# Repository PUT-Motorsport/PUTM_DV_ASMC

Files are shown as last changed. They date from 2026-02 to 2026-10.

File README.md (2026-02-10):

# ASMC: Autonomous System Main Controller

## Project Overview
The **ASMC (Autonomous System Main Controller)** is a central electronic control unit designed for a Formula Student racing vehicle. Its primary objective is to integrate the critical subsystems required for autonomous operation in compliance with the **Formula Student Rules 2026**. 

This board serves as a robust interface between the high-level autonomous compute unit and the vehicle's hardware, ensuring safety, reliable power distribution, and real-time status signaling.

## Key Functionalities

### 1. Power Management & Distribution
* **Peripheral Supply**: Provides regulated and protected power to sensors, actuators, and processing units necessary for the Autonomous System (AS).
* **LVS Compliance**: Operates within the Low Voltage System (LVS) limits (max 60V DC) and ensures proper grounding to the chassis.
* **Overcurrent Protection**: Integrated protection for all connected devices to prevent hardware failure during dynamic disciplines.

### 2. Autonomous System Signaling (ASSI & AMI)
* **ASSI Control**: Drives three Autonomous System Status Indicators (ASSI) positioned on the sides and rear of the vehicle.
* **Visual Logic**: Implements mandatory lighting patterns (e.g., 2–5 Hz flashing for "Driving" and "Emergency" states).
* **Acoustic Warning**: Manages the intermittent sound signal (80–90 dBA) required during the "AS Emergency" state.
* **Mission Selection**: Interfaces with the Autonomous Mission Indicator (AMI) to allow manual mission selection and status feedback without external tools.

### 3. Safety & Braking Interface (ASB/EBS)
* **EBS Data Processing**: Receives and processes critical data from the Emergency Brake System (EBS).
* **SCS Monitoring**: Continuously monitors System Critical Signals (SCS). Any failure (e.g., open circuit or data corruption) triggers a safe state transition within <500ms.
* **SDC & RES Integration**: Interfaces with the Shutdown Circuit (SDC) and the Remote Emergency System (RES) to allow for immediate vehicle shutdown.

## Technical Compliance
Designed according to the **T14 (Autonomous System)** and **T15 (Autonomous System Brake)** sections of the FS 2026 rulebook.

* **AS Status Flowchart**: The board logic follows the mandatory state machine (Off, Ready, Driving, Emergency, Finished).
* **Failsafe Design**: Ensures that loss of power or signal defaults the vehicle to an "AS Emergency" state, engaging the mechanical brakes.
* **Data Logging**: Provides necessary signal outputs to the official Formula Student Data Logger for competition transparency.

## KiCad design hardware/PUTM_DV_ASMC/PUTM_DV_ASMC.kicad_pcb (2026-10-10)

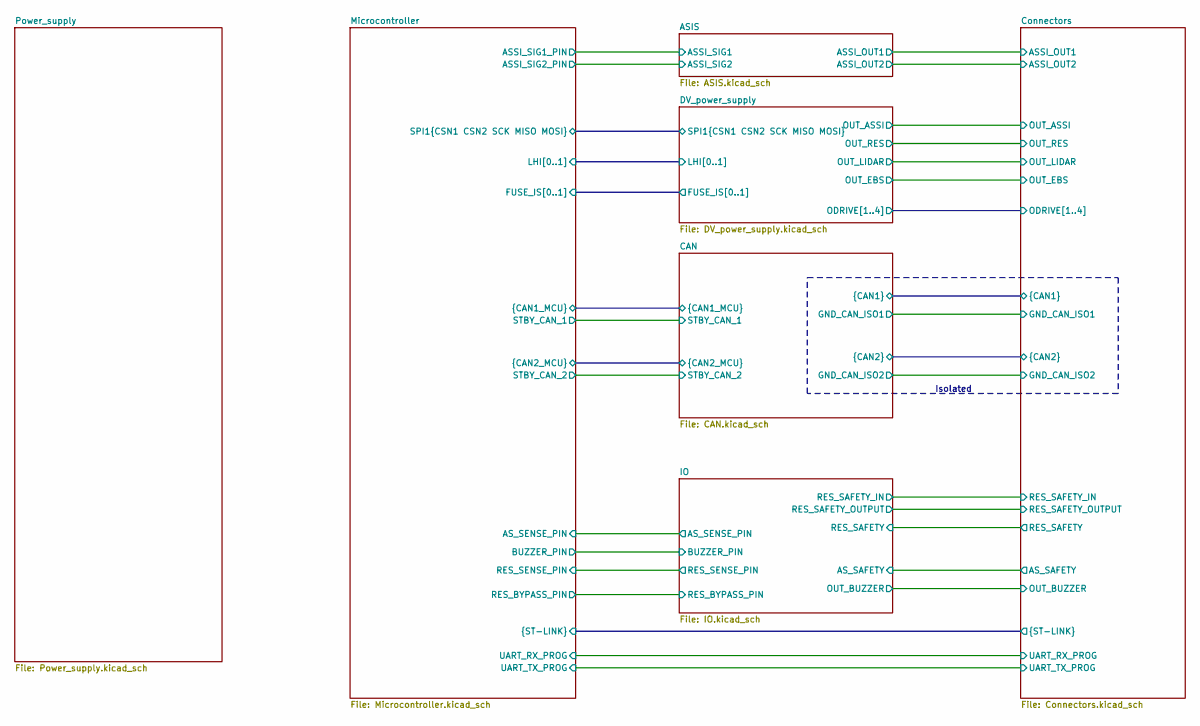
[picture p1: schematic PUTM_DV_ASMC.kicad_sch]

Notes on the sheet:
Isolated

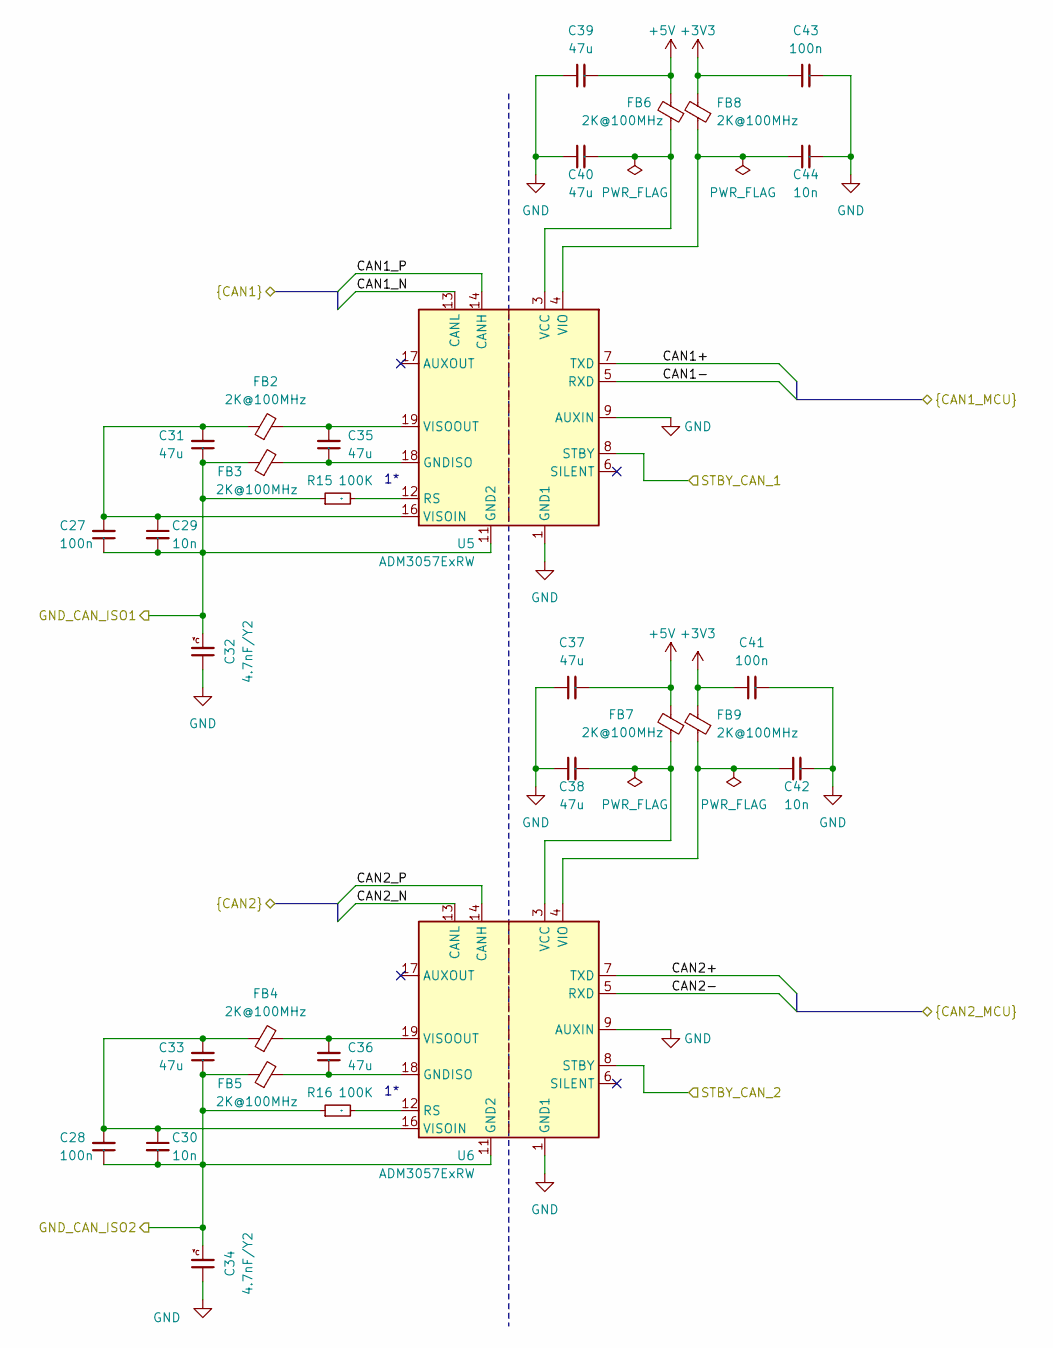
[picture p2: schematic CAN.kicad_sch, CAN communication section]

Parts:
C27, C28, C41, C43: 100n; C_0603_1608Metric_Pad1.08x0.95mm_HandSolder; Mouser Part Number .
C29, C30, C42, C44: 10n; C_0603_1608Metric_Pad1.08x0.95mm_HandSolder; Mouser Part Number .
C31, C33, C35, C36, C37, C38, C39, C40: 47u; C_0805_2012Metric_Pad1.18x1.45mm_HandSolder; Mouser Part Number .
C32, C34: 4.7nF/Y2; CAPC5728X280N; Mouser Part Number 791-S252B222K502CT
FB2, FB3, FB4, FB5, FB6, FB7, FB8, FB9: 2K@100MHz; L_0805_2012Metric_Pad1.05x1.20mm_HandSolder; Mouser Part Number 623-2508052027Y1
R15, R16: 100K; R_0603_1608Metric_Pad0.98x0.95mm_HandSolder; Mouser Part Number .
U5, U6: ADM3057ExRW; SOIC-20W_7.5x12.8mm_P1.27mm; Mouser Part Number 584-ADM3057EBRWZ

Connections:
+3V3: C41.1, C43.1, FB8.2, FB9.2; also elsewhere on the board
+5V: C37.2, C39.2, FB6.2, FB7.2; also elsewhere on the board
/CAN/CAN1+: U5.7 (TXD); also elsewhere on the board
/CAN/CAN1-: U5.5 (RXD); also elsewhere on the board
/CAN/CAN1_N: U5.13 (CANL); also elsewhere on the board
/CAN/CAN1_P: U5.14 (CANH); also elsewhere on the board
/CAN/CAN2+: U6.7 (TXD); also elsewhere on the board
/CAN/CAN2-: U6.5 (RXD); also elsewhere on the board
/CAN/CAN2_N: U6.13 (CANL); also elsewhere on the board
/CAN/CAN2_P: U6.14 (CANH); also elsewhere on the board
/CAN/GND_CAN_ISO1: C27.1, C29.2, C31.1, C32.2, FB3.1, R15.1, U5.11 (GND2), U5.15 (GND2); also elsewhere on the board
/CAN/GND_CAN_ISO2: C28.1, C30.2, C33.1, C34.2, FB5.1, R16.1, U6.11 (GND2), U6.15 (GND2); also elsewhere on the board
/CAN/STBY_CAN_1: U5.8 (STBY); also elsewhere on the board
/CAN/STBY_CAN_2: U6.8 (STBY); also elsewhere on the board
GND: C32.1, C34.1, C37.1, C38.1, C39.1, C40.1, C41.2, C42.2, C43.2, C44.2, U5.1 (GND1), U5.2 (GND1), U5.9 (AUXIN), U5.10 (GND1), U6.1 (GND1), U6.2 (GND1), U6.9 (AUXIN), U6.10 (GND1); also elsewhere on the board
unnamed: C35.1, FB3.2, U5.18 (GNDISO), U5.20 (GNDISO)
unnamed: C36.1, FB5.2, U6.18 (GNDISO), U6.20 (GNDISO)
unnamed: R15.2, U5.12 (RS)
unnamed: C40.2, FB6.1, U5.3 (VCC)
unnamed: C44.1, FB8.1, U5.4 (VIO)
unnamed: C27.2, C29.1, C31.2, FB2.1, U5.16 (VISOIN)
unnamed: C35.2, FB2.2, U5.19 (VISOOUT)
unnamed: R16.2, U6.12 (RS)
unnamed: C38.2, FB7.1, U6.3 (VCC)
unnamed: C42.1, FB9.1, U6.4 (VIO)
unnamed: C28.2, C30.1, C33.2, FB4.1, U6.16 (VISOIN)
unnamed: C36.2, FB4.2, U6.19 (VISOOUT)

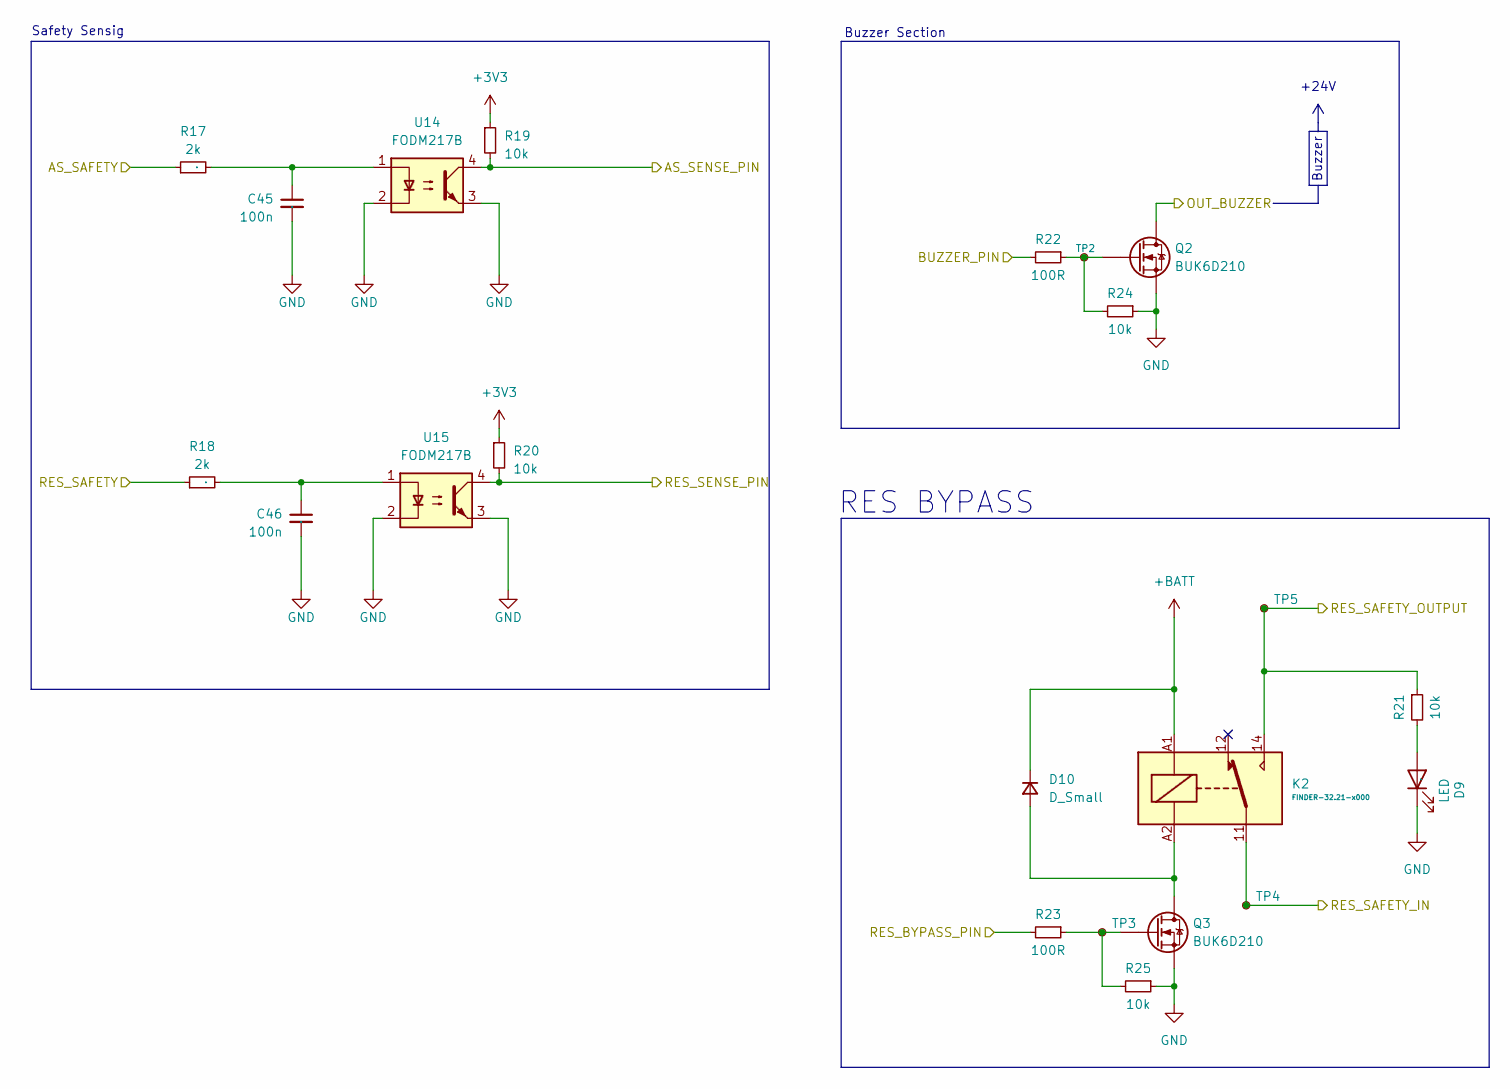
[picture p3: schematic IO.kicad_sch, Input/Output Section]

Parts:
C45, C46: 100n; C_0603_1608Metric_Pad1.08x0.95mm_HandSolder; Mouser Part Number .
D9: LED; LED_0603_1608Metric_Pad1.05x0.95mm_HandSolder; Mouser Part Number .
D10: D_Small; D_0805_2012Metric_Pad1.15x1.40mm_HandSolder
K2: FINDER-32.21-x000; Relay_SPDT_Finder_32.21-x000
Q2, Q3: BUK6D210; Diodes_UDFN2020-6_Type-F
R17, R18: 2k; R_0603_1608Metric_Pad0.98x0.95mm_HandSolder; Mouser Part Number .
R19, R20: 10k; R_0603_1608Metric_Pad0.98x0.95mm_HandSolder; Mouser Part Number .
R21: 10k; R_1206_3216Metric_Pad1.30x1.75mm_HandSolder
R22, R23: 100R; R_0603_1608Metric
R24, R25: 10k; R_0603_1608Metric
TP2: TestPoint_Small; TestPoint_Pad_D1.0mm
TP3, TP4, TP5: TestPoint_Small
U14, U15: FODM217B; SOP-4_4.4x2.6mm_P1.27mm; Mouser Part Number 512-FODM217B

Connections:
+3V3: R19.1, R20.1; also elsewhere on the board
+BATT: D10.1 (K), K2.A1; also elsewhere on the board
/Connectors/AS_SAFETY: R17.1; also elsewhere on the board
/Connectors/OUT_BUZZER: Q2.1 (D), Q2.2 (D), Q2.5 (D), Q2.6 (D), Q2.7 (D); also elsewhere on the board
/Connectors/RES_SAFETY: R18.1; also elsewhere on the board
/Connectors/RES_SAFETY_IN: K2.11, TP4.1; also elsewhere on the board
/Connectors/RES_SAFETY_OUTPUT: K2.14, R21.1, TP5.1; also elsewhere on the board
/IO/AS_SENSE_PIN: R19.2, U14.4; also elsewhere on the board
/IO/BUZZER_PIN: R22.2; also elsewhere on the board
/IO/RES_BYPASS_PIN: R23.2; also elsewhere on the board
/IO/RES_SENSE_PIN: R20.2, U15.4; also elsewhere on the board
GND: C45.2, C46.2, D9.1 (K), Q2.4 (S), Q2.8 (S), Q3.4 (S), Q3.8 (S), R24.1, R25.1, U14.2, U14.3, U15.2, U15.3; also elsewhere on the board
unnamed: C45.1, R17.2, U14.1
unnamed: C46.1, R18.2, U15.1
unnamed: D9.2 (A), R21.2
unnamed: D10.2 (A), K2.A2, Q3.1 (D), Q3.2 (D), Q3.5 (D), Q3.6 (D), Q3.7 (D)
unnamed: Q2.3 (G), R22.1, R24.2, TP2.1 (1_1)
unnamed: Q3.3 (G), R23.1, R25.2, TP3.1

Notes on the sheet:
+24V
Buzzer Section
Buzzer
Safety Sensig
RES BYPASS

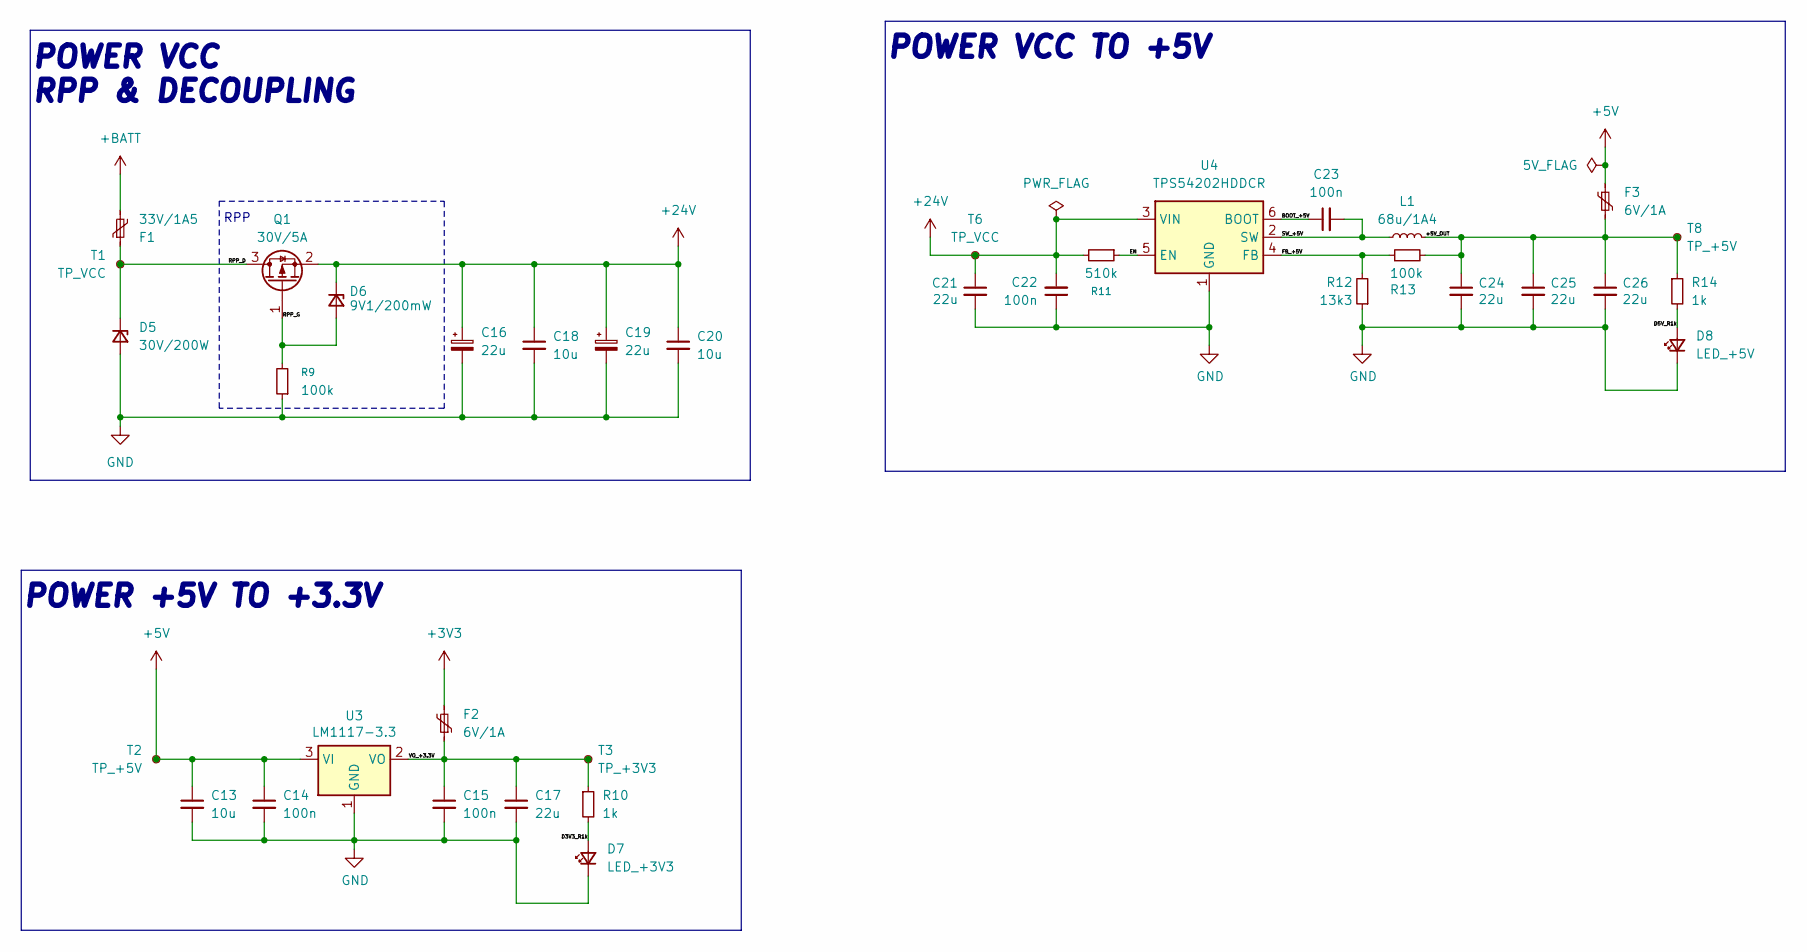
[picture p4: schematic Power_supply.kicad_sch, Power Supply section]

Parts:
C13, C18, C20: 10u; C_0805_2012Metric_Pad1.18x1.45mm_HandSolder; Mouser Part Number 81-GRM21BR61H106KE3L
C14, C15, C23: 100n; C_0603_1608Metric_Pad1.08x0.95mm_HandSolder; Mouser Part Number 81-GCJ188R71H104KA2D
C16, C19: 22u; CP_Elec_5x5.8; Mouser Part Number 647-UCM1H220MCL1GS
C17: 22u; C_0805_2012Metric_Pad1.18x1.45mm_HandSolder; Mouser Part Number 810-C2012X5R1V226MAC
C21, C24, C25, C26: 22u; C_0805_2012Metric_Pad1.18x1.45mm_HandSolder; Manufacturer_Part_Number CL21A107MQYNNWE; Mouser Part Number 810-C2012X5R1V226MAC
C22: 100n; C_0603_1608Metric_Pad1.08x0.95mm_HandSolder; Manufacturer_Part_Number C0603C104J3RACTU; Mouser Part Number 81-GCJ188R71H104KA2D
D5: 30V/200W; D_SOD-123; Mouser Part Number 750-TV02W260-G
D6: 9V1/200mW; D_SOD-323_HandSoldering; Mouser Part Number 833-MMXZ5239B-TP
D7: LED_+3V3; LED_0603_1608Metric_Pad1.05x0.95mm_HandSolder
D8: LED_+5V; LED_0603_1608Metric_Pad1.05x0.95mm_HandSolder
F1: 33V/1A5; Fuse_2920_7451Metric_Pad2.10x5.45mm_HandSolder; Mouser Part Number 530-0ZCF0075AF2C
F2, F3: 6V/1A; Fuse_0805_2012Metric_Pad1.15x1.40mm_HandSolder; Mouser Part Number 650-PICOSMDC050S-2
L1: 68u/1A4; L_TDK_VLS6045EX_VLS6045AF; Mouser Part Number 810-VLS6045EX-680M
Q1: 30V/5A; SOT-23-3; Mouser Part Number 78-SI2347DS-T1-GE3
R9: 100k; R_0603_1608Metric_Pad0.98x0.95mm_HandSolder; Mouser Part Number 71-CRCW0603100KFKEAH
R10, R14: 1k; R_0603_1608Metric_Pad0.98x0.95mm_HandSolder; Mouser Part Number 71-CRCW0603-1.0K-E3
R11: 510k; R_0603_1608Metric_Pad0.98x0.95mm_HandSolder; Mouser Part Number 71-CRCW0603J-510K-E3
R12: 13k3; R_0603_1608Metric_Pad0.98x0.95mm_HandSolder; Manufacturer_Part_Number RT0603DRE0713K3L; Mouser Part Number 71-CRCW0603-13.3K-E3
R13: 100k; R_0603_1608Metric_Pad0.98x0.95mm_HandSolder; Manufacturer_Part_Number RT0603DRE07100KL; Mouser Part Number 71-CRCW0603100KFKEAH
T1, T6: TP_VCC; TestPoint_Pad_1.0x1.0mm
T2, T8: TP_+5V; TestPoint_Pad_1.0x1.0mm
T3: TP_+3V3; TestPoint_Pad_1.0x1.0mm
U3: LM1117-3.3; SOT-223-3_TabPin2; Mouser Part Number 926-LM1117MPX3.3NOPB
U4: TPS54202HDDCR; SOT-23-6_Handsoldering; Mouser Part Number 595-TPS54202HDDCR

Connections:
+3V3: F2.2; also elsewhere on the board
+5V: C13.1, C14.1, F3.1, T2.1 (1_1), U3.3 (VI); also elsewhere on the board
+24V: C16.1, C18.1, C19.1, C20.1, C21.1, C22.2, D6.1 (K), Q1.2 (S), R11.2, T6.1 (1_1), U4.3 (VIN)
+BATT: F1.2; also elsewhere on the board
/Power_supply/+5V_OUT: C24.1, C25.1, C26.1, F3.2, L1.2, R13.2, R14.1, T8.1 (1_1)
/Power_supply/BOOT_+5V: C23.1, U4.6 (BOOT)
/Power_supply/D3V3_R1k: D7.2 (A), R10.2
/Power_supply/D5V_R1k: D8.2 (A), R14.2
/Power_supply/EN: R11.1, U4.5 (EN)
/Power_supply/FB_+5V: R12.2, R13.1, U4.4 (FB)
/Power_supply/RPP_D: D5.1 (K), F1.1, Q1.3 (D), T1.1 (1_1)
/Power_supply/RPP_G: D6.2 (A), Q1.1 (G), R9.2
/Power_supply/SW_+5V: C23.2, L1.1, U4.2 (SW)
/Power_supply/VO_+3.3V: C15.1, C17.1, F2.1, R10.1, T3.1 (1_1), U3.2 (VO)
GND: C13.2, C14.2, C15.2, C16.2, C17.2, C18.2, C19.2, C20.2, C21.2, C22.1, C24.2, C25.2, C26.2, D5.2 (A), D7.1 (K), D8.1 (K), R9.1, R12.1, U3.1 (GND), U4.1 (GND); also elsewhere on the board

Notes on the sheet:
POWER +5V TO +3.3V
POWER VCC RPP & DECOUPLING
POWER VCC TO +5V
RPP

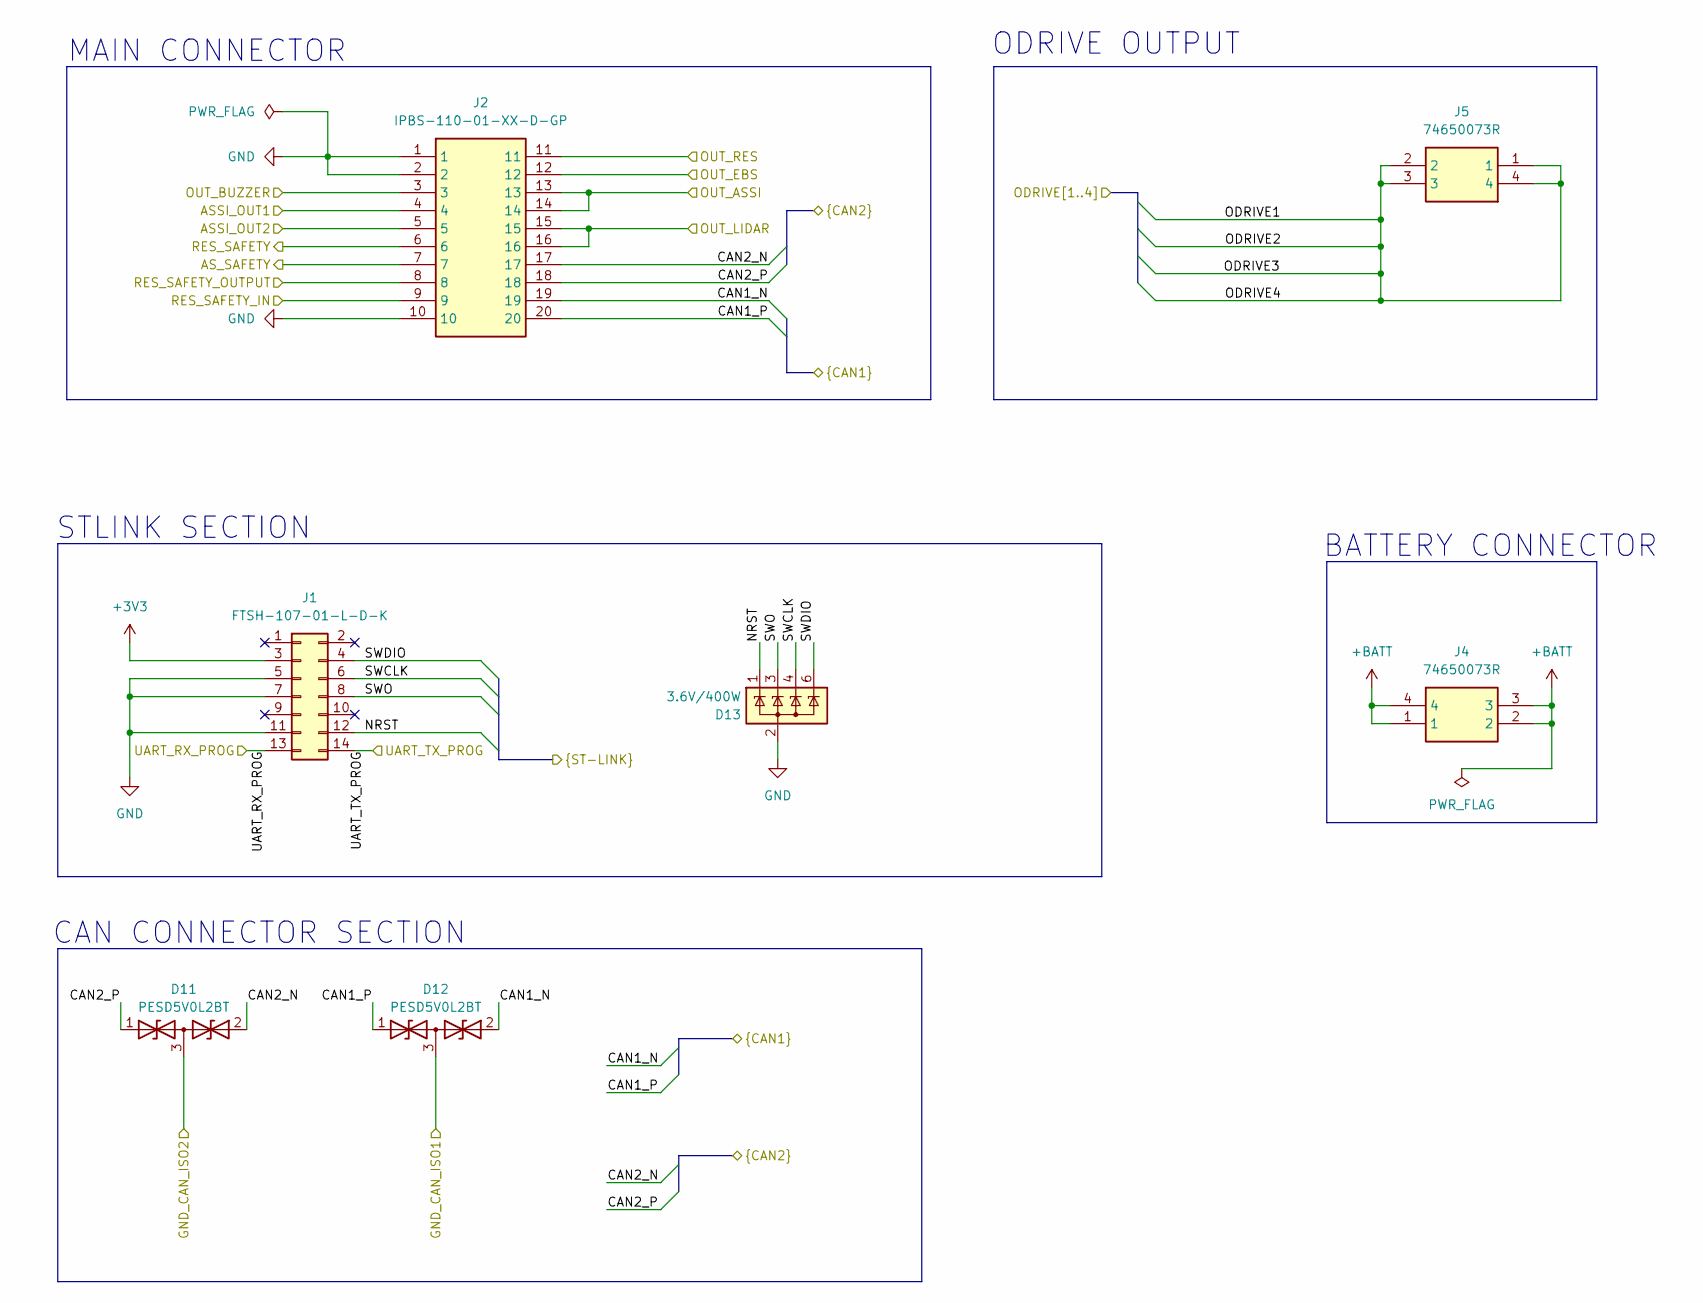
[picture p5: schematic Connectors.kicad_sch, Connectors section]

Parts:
D11, D12: PESD5V0L2BT; SOT-23_Handsoldering; Mouser Part Number 771-PESD5V0L2BT-QR
D13: 3.6V/400W; SOT-23-6; Manufacturer_Part_Number ESDS304DBVR; Mouser Part Number 595-ESDS304DBVR
J1: FTSH-107-01-L-D-K; FTSH-107-XX-YYY-D-K; Mouser Part Number 200-FTSH10701LDK
J2: IPBS-110-01-XX-D-GP; IPBS11001TDGP; PARTREV M; Mouser Part Number 200-IPBS11001TDGP
J4, J5: 74650073R; Mouser Part Number 710-74650073R

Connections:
+3V3: J1.3; also elsewhere on the board
+BATT: J4.1, J4.2, J4.3, J4.4; also elsewhere on the board
/ASIS/ASSI_OUT1: J2.4; also elsewhere on the board
/ASIS/ASSI_OUT2: J2.5; also elsewhere on the board
/CAN/CAN1_N: D12.2 (A2), J2.19; also elsewhere on the board
/CAN/CAN1_P: D12.1 (A1), J2.20; also elsewhere on the board
/CAN/CAN2_N: D11.2 (A2), J2.17; also elsewhere on the board
/CAN/CAN2_P: D11.1 (A1), J2.18; also elsewhere on the board
/CAN/GND_CAN_ISO1: D12.3 (common); also elsewhere on the board
/CAN/GND_CAN_ISO2: D11.3 (common); also elsewhere on the board
/Connectors/AS_SAFETY: J2.7; also elsewhere on the board
/Connectors/NRST: D13.1 (A), J1.12; also elsewhere on the board
/Connectors/ODRIVE4: J5.1, J5.2, J5.3, J5.4; also elsewhere on the board
/Connectors/OUT_ASSI: J2.13, J2.14; also elsewhere on the board
/Connectors/OUT_BUZZER: J2.3; also elsewhere on the board
/Connectors/OUT_EBS: J2.12; also elsewhere on the board
/Connectors/OUT_LIDAR: J2.15, J2.16; also elsewhere on the board
/Connectors/OUT_RES: J2.11; also elsewhere on the board
/Connectors/RES_SAFETY: J2.6; also elsewhere on the board
/Connectors/RES_SAFETY_IN: J2.9; also elsewhere on the board
/Connectors/RES_SAFETY_OUTPUT: J2.8; also elsewhere on the board
/Connectors/SWCLK: D13.4 (A), J1.6; also elsewhere on the board
/Connectors/SWDIO: D13.6 (A), J1.4; also elsewhere on the board
/Connectors/SWO: D13.3 (A), J1.8; also elsewhere on the board
/Connectors/UART_RX_PROG: J1.13; also elsewhere on the board
/Connectors/UART_TX_PROG: J1.14; also elsewhere on the board
GND: D13.2 (K), D13.5 (NC), J1.5, J1.7, J1.11, J2.1, J2.2, J2.10; also elsewhere on the board

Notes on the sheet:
BATTERY CONNECTOR
STLINK SECTION
CAN CONNECTOR SECTION
MAIN CONNECTOR
ODRIVE OUTPUT

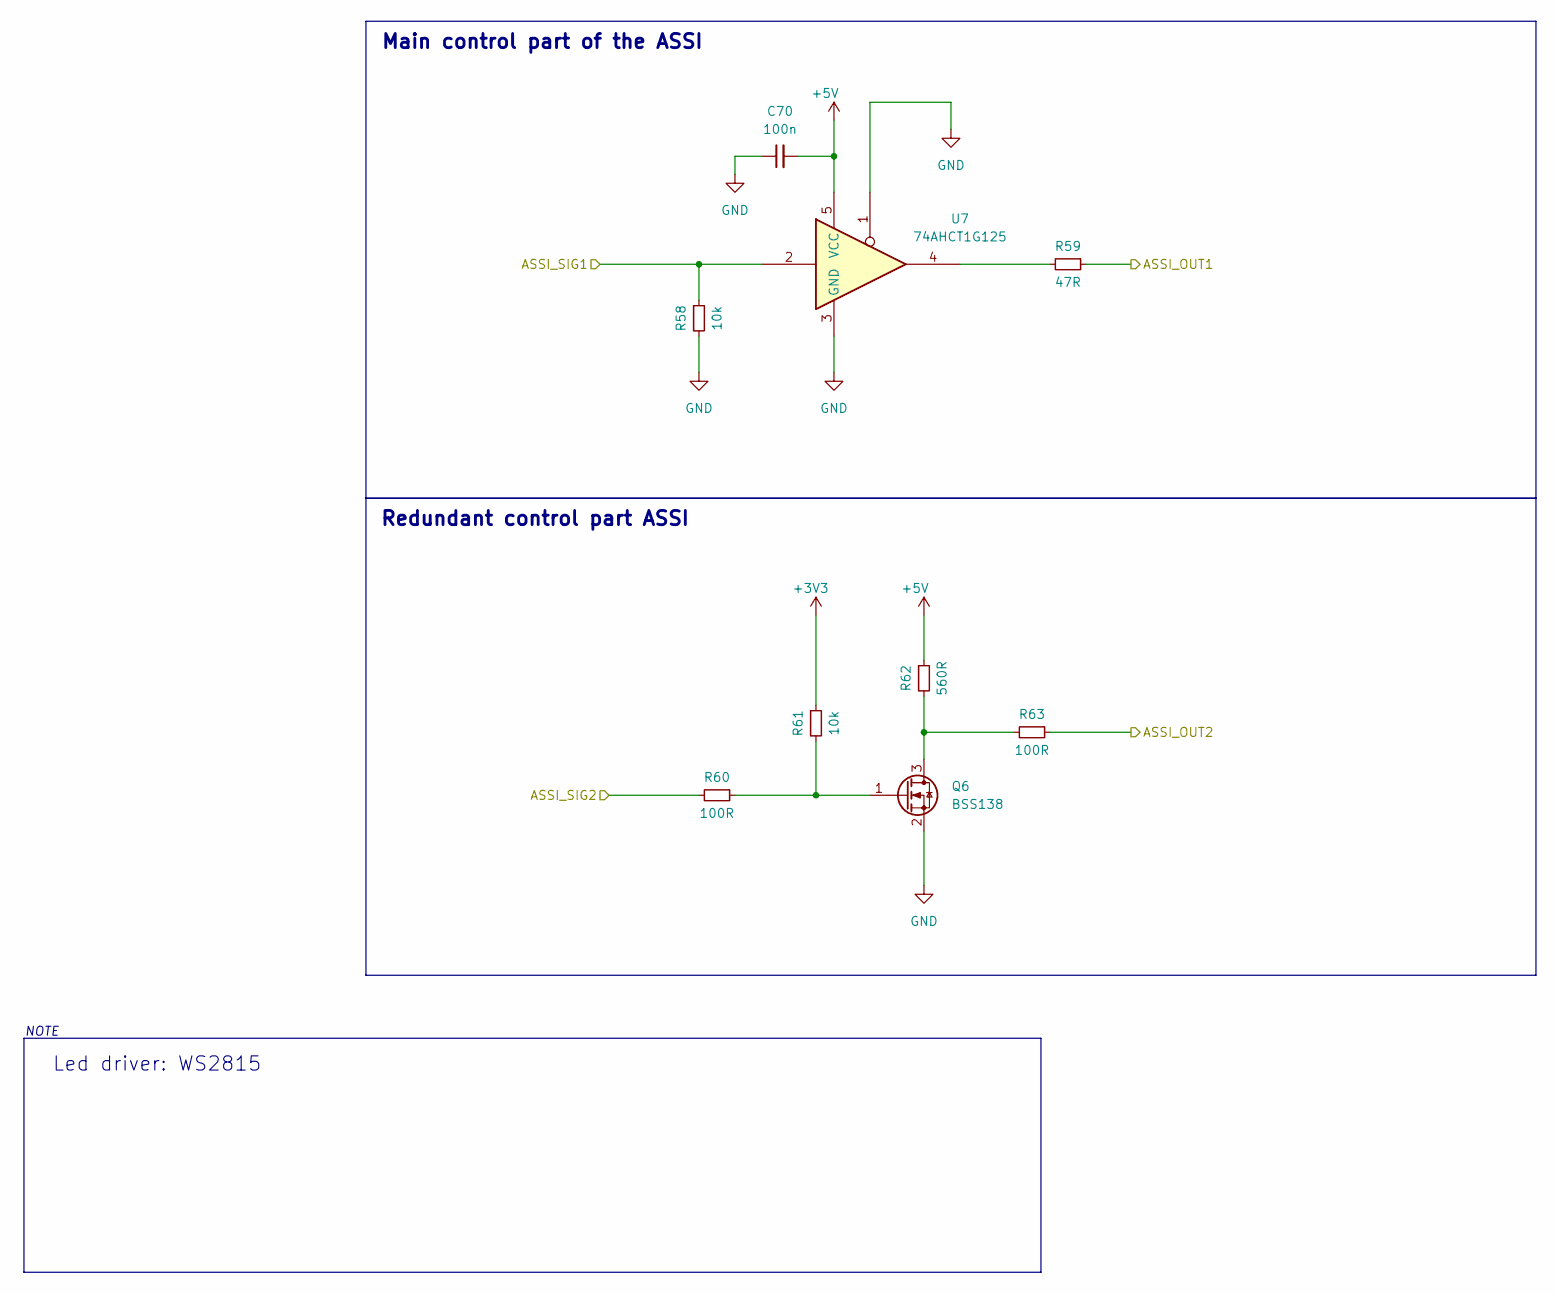
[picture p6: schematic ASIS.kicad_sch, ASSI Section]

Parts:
C70: 100n; C_0603_1608Metric_Pad1.08x0.95mm_HandSolder; Mouser Part Number .
Q6: BSS138; SOT-23
R58, R61: 10k; R_0603_1608Metric
R59: 47R; R_0603_1608Metric
R60, R63: 100R; R_0603_1608Metric
R62: 560R; R_0603_1608Metric
U7: 74AHCT1G125; SOT-23-5

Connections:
+3V3: R61.1; also elsewhere on the board
+5V: C70.2, R62.1, U7.5 (VCC); also elsewhere on the board
/ASIS/ASSI_OUT1: R59.1; also elsewhere on the board
/ASIS/ASSI_OUT2: R63.1; also elsewhere on the board
/ASIS/ASSI_SIG1: R58.1, U7.2; also elsewhere on the board
/ASIS/ASSI_SIG2: R60.2; also elsewhere on the board
GND: C70.1, Q6.2 (S), R58.2, U7.1, U7.3 (GND); also elsewhere on the board
unnamed: Q6.3 (D), R62.2, R63.2
unnamed: Q6.1 (G), R60.1, R61.2
unnamed: R59.2, U7.4

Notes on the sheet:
Led driver: WS2815
Redundant control part ASSI
Main control part of the ASSI
NOTE

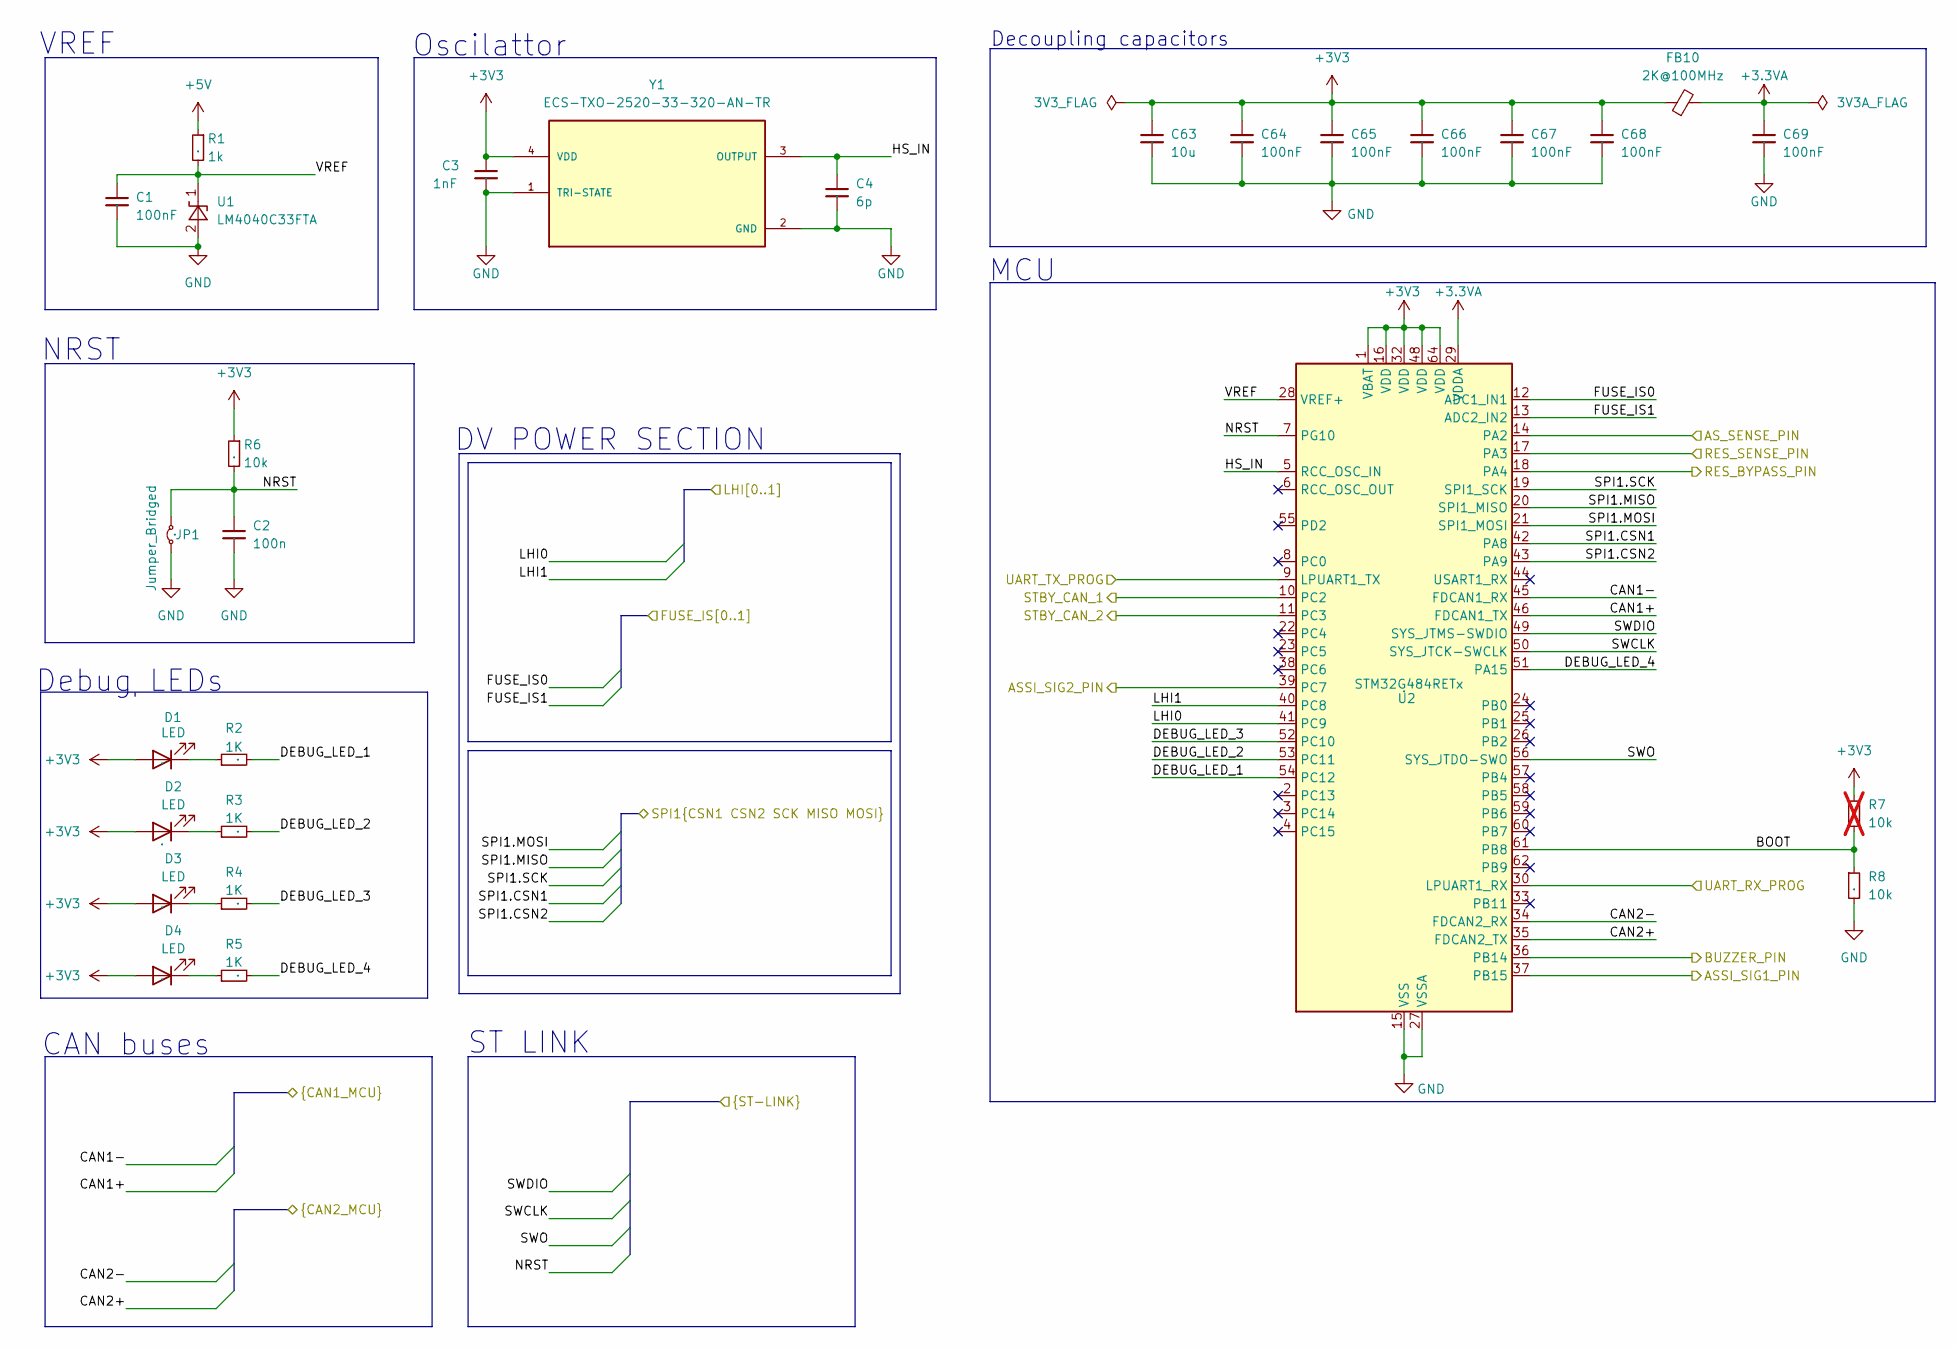
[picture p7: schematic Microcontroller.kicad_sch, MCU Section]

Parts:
C1, C64, C65, C66, C67, C68, C69: 100nF; C_0603_1608Metric_Pad1.08x0.95mm_HandSolder; Mouser Part Number .
C2: 100n; C_0603_1608Metric; Mouser Part Number .
C3: 1nF; C_0603_1608Metric_Pad1.08x0.95mm_HandSolder; Mouser Part Number .
C4: 6p; C_0603_1608Metric_Pad1.08x0.95mm_HandSolder; Mouser Part Number .
C63: 10u; C_0805_2012Metric_Pad1.18x1.45mm_HandSolder; Mouser Part Number .
D1, D2, D3, D4: LED; LED_0603_1608Metric_Pad1.05x0.95mm_HandSolder; Mouser Part Number .
FB10: 2K@100MHz; L_0805_2012Metric_Pad1.05x1.20mm_HandSolder; Mouser Part Number 623-2508052027Y1
JP1: Jumper_Bridged; SolderJumper-2_P1.3mm_Open_TrianglePad1.0x1.5mm; Mouser Part Number .
R1: 1k; R_0603_1608Metric; Mouser Part Number .
R2, R3, R4, R5: 1K; R_0603_1608Metric_Pad0.98x0.95mm_HandSolder; Mouser Part Number .
R6, R8: 10k; R_0603_1608Metric; Mouser Part Number .
R7: 10k; R_0603_1608Metric; Mouser Part Number .; not fitted
U1: LM4040C33FTA; SOT-23; Mouser Part Number 621-LM4040C33FTA
U2: STM32G484RETx; LQFP-64_10x10mm_P0.5mm; Mouser Part Number .
Y1: ECS-TXO-2520-33-320-AN-TR; OSC_ECS-TXO-2520-33-320-AN-TR; PARTREV 2017

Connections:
+3.3VA: C69.1, FB10.2, U2.29 (VDDA)
+3V3: C3.1, C63.1, C64.1, C65.1, C66.1, C67.1, C68.1, D1.2 (A), D2.2 (A), D3.2 (A), D4.2 (A), FB10.1, R6.1, R7.1, U2.1 (VBAT), U2.16 (VDD), U2.32 (VDD), U2.48 (VDD), U2.64 (VDD), Y1.4 (VDD); also elsewhere on the board
+5V: R1.1; also elsewhere on the board
/ASIS/ASSI_SIG1: U2.37 (PB15); also elsewhere on the board
/ASIS/ASSI_SIG2: U2.39 (PC7); also elsewhere on the board
/CAN/CAN1+: U2.46 (FDCAN1_TX); also elsewhere on the board
/CAN/CAN1-: U2.45 (FDCAN1_RX); also elsewhere on the board
/CAN/CAN2+: U2.35 (FDCAN2_TX); also elsewhere on the board
/CAN/CAN2-: U2.34 (FDCAN2_RX); also elsewhere on the board
/CAN/STBY_CAN_1: U2.10 (PC2); also elsewhere on the board
/CAN/STBY_CAN_2: U2.11 (PC3); also elsewhere on the board
/Connectors/NRST: C2.1, JP1.2 (B), R6.2, U2.7 (PG10); also elsewhere on the board
/Connectors/SWCLK: U2.50 (SYS_JTCK-SWCLK); also elsewhere on the board
/Connectors/SWDIO: U2.49 (SYS_JTMS-SWDIO); also elsewhere on the board
/Connectors/SWO: U2.56 (SYS_JTDO-SWO); also elsewhere on the board
/Connectors/UART_RX_PROG: U2.30 (LPUART1_RX); also elsewhere on the board
/Connectors/UART_TX_PROG: U2.9 (LPUART1_TX); also elsewhere on the board
/DV_power_supply/FUSE_IS0: U2.12 (ADC1_IN1); also elsewhere on the board
/DV_power_supply/FUSE_IS1: U2.13 (ADC2_IN2); also elsewhere on the board
/DV_power_supply/LHI0: U2.41 (PC9); also elsewhere on the board
/DV_power_supply/LHI1: U2.40 (PC8); also elsewhere on the board
/DV_power_supply/SPI1.CSN1: U2.42 (PA8); also elsewhere on the board
/DV_power_supply/SPI1.CSN2: U2.43 (PA9); also elsewhere on the board
/DV_power_supply/SPI1.MISO: U2.20 (SPI1_MISO); also elsewhere on the board
/DV_power_supply/SPI1.MOSI: U2.21 (SPI1_MOSI); also elsewhere on the board
/DV_power_supply/SPI1.SCK: U2.19 (SPI1_SCK); also elsewhere on the board
/IO/AS_SENSE_PIN: U2.14 (PA2); also elsewhere on the board
/IO/BUZZER_PIN: U2.36 (PB14); also elsewhere on the board
/IO/RES_BYPASS_PIN: U2.18 (PA4); also elsewhere on the board
/IO/RES_SENSE_PIN: U2.17 (PA3); also elsewhere on the board
/Microcontroller/BOOT: R7.2, R8.1, U2.61 (PB8)
/Microcontroller/DEBUG_LED_1: R2.2, U2.54 (PC12)
/Microcontroller/DEBUG_LED_2: R3.2, U2.53 (PC11)
/Microcontroller/DEBUG_LED_3: R4.2, U2.52 (PC10)
/Microcontroller/DEBUG_LED_4: R5.2, U2.51 (PA15)
/Microcontroller/HS_IN: C4.1, U2.5 (RCC_OSC_IN), Y1.3 (OUTPUT)
/Microcontroller/VREF: C1.1, R1.2, U1.1 (K), U2.28 (VREF+)
GND: C1.2, C2.2, C3.2, C4.2, C63.2, C64.2, C65.2, C66.2, C67.2, C68.2, C69.2, JP1.1 (A), R8.2, U1.2 (A), U2.15 (VSS), U2.27 (VSSA), U2.31 (VSS), U2.47 (VSS), U2.63 (VSS), Y1.1 (TRI-STATE), Y1.2 (GND); also elsewhere on the board
unnamed: D1.1 (K), R2.1
unnamed: D2.1 (K), R3.1
unnamed: D3.1 (K), R4.1
unnamed: D4.1 (K), R5.1

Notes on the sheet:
DV POWER SECTION
NRST
Decoupling capacitors
Debug LEDs
CAN buses
Oscilattor
MCU
VREF
ST LINK

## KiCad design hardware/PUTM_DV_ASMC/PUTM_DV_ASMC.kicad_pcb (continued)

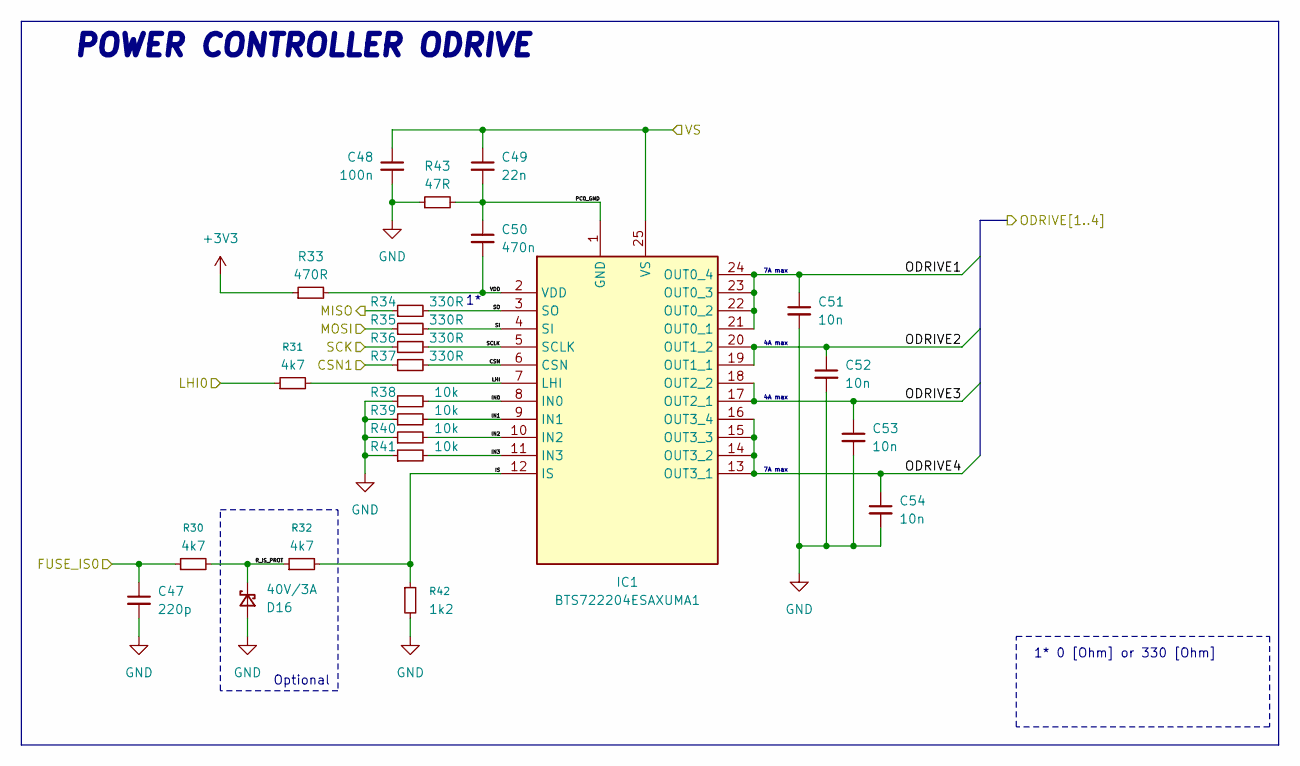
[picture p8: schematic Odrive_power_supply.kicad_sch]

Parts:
C47: 220p; C_0603_1608Metric_Pad1.08x0.95mm_HandSolder; Mouser Part Number 81-GCM1885C1H221JA6J
C48: 100n; C_0603_1608Metric_Pad1.08x0.95mm_HandSolder; Mouser Part Number 81-GCJ188R71H104KA2D
C49: 22n; C_0603_1608Metric_Pad1.08x0.95mm_HandSolder; Mouser Part Number GCE188R71H223KA01D
C50: 470n; C_0603_1608Metric_Pad1.08x0.95mm_HandSolder; Mouser Part Number 810-C1608X7R1H474K0E
C51, C52, C53, C54: 10n; C_0603_1608Metric_Pad1.08x0.95mm_HandSolder; Mouser Part Number 81-GCE188R71H103KA1D
D16: 40V/3A; D_SOD-123F; Mouser Part Number 637-SKL34
IC1: BTS722204ESAXUMA1; SOP65P600X115-25N; Mouser Part Number 726-BTS722204ESAXUMA
R30, R31, R32: 4k7; R_0603_1608Metric_Pad0.98x0.95mm_HandSolder; Mouser Part Number 71-CRCW0603-4.7K-E3
R33: 470R; R_0603_1608Metric_Pad0.98x0.95mm_HandSolder; Mouser Part Number 71-CRCW0603J-470-E3
R34, R35, R36, R37: 330R; R_0603_1608Metric_Pad0.98x0.95mm_HandSolder; Mouser Part Number 71-CRCW0603-330-E3
R38, R39, R40, R41: 10k; R_0603_1608Metric_Pad0.98x0.95mm_HandSolder; Mouser Part Number 71-CRCW060310K0FKEAH
R42: 1k2; R_0603_1608Metric_Pad0.98x0.95mm_HandSolder; Mouser Part Number 71-CRCW0603-1.2K-E3
R43: 47R; R_0603_1608Metric_Pad0.98x0.95mm_HandSolder; Mouser Part Number 71-RCS060347R0JNEA

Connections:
+3V3: R33.1; also elsewhere on the board
+BATT: C48.1, C49.1, IC1.25 (VS); also elsewhere on the board
/Connectors/ODRIVE4: C51.1, C52.1, C53.1, C54.1, IC1.13 (OUT3_1), IC1.14 (OUT3_2), IC1.15 (OUT3_3), IC1.16 (OUT3_4), IC1.17 (OUT2_1), IC1.18 (OUT2_2), IC1.19 (OUT1_1), IC1.20 (OUT1_2), IC1.21 (OUT0_1), IC1.22 (OUT0_2), IC1.23 (OUT0_3), IC1.24 (OUT0_4); also elsewhere on the board
/DV_power_supply/FUSE_IS0: C47.1, R30.1; also elsewhere on the board
/DV_power_supply/LHI0: R31.1; also elsewhere on the board
/DV_power_supply/Odrive_power_supply/CSN: IC1.6 (CSN), R37.2
/DV_power_supply/Odrive_power_supply/IN0: IC1.8 (IN0), R38.2
/DV_power_supply/Odrive_power_supply/IN1: IC1.9 (IN1), R39.2
/DV_power_supply/Odrive_power_supply/IN2: IC1.10 (IN2), R40.2
/DV_power_supply/Odrive_power_supply/IN3: IC1.11 (IN3), R41.2
/DV_power_supply/Odrive_power_supply/IS: IC1.12 (IS), R32.2, R42.1
/DV_power_supply/Odrive_power_supply/LHI: IC1.7 (LHI), R31.2
/DV_power_supply/Odrive_power_supply/PC0_GND: C49.2, C50.1, IC1.1 (GND), R43.2
/DV_power_supply/Odrive_power_supply/R_IS_PROT: D16.1 (K), R30.2, R32.1
/DV_power_supply/Odrive_power_supply/SCLK: IC1.5 (SCLK), R36.2
/DV_power_supply/Odrive_power_supply/SI: IC1.4 (SI), R35.2
/DV_power_supply/Odrive_power_supply/SO: IC1.3 (SO), R34.2
/DV_power_supply/Odrive_power_supply/VDD: C50.2, IC1.2 (VDD), R33.2
/DV_power_supply/SPI1.CSN1: R37.1; also elsewhere on the board
/DV_power_supply/SPI1.MISO: R34.1; also elsewhere on the board
/DV_power_supply/SPI1.MOSI: R35.1; also elsewhere on the board
/DV_power_supply/SPI1.SCK: R36.1; also elsewhere on the board
GND: C47.2, C48.2, C51.2, C52.2, C53.2, C54.2, D16.2 (A), R38.1, R39.1, R40.1, R41.1, R42.2, R43.1; also elsewhere on the board

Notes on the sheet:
4A max
Optional
1* 0 [Ohm] or 330 [Ohm]
POWER CONTROLLER ODRIVE
7A max

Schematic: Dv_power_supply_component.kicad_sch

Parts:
C55: 220p; C_0603_1608Metric_Pad1.08x0.95mm_HandSolder; Mouser Part Number 81-GCM1885C1H221JA6J
C56: 100n; C_0603_1608Metric_Pad1.08x0.95mm_HandSolder; Mouser Part Number 81-GCJ188R71H104KA2D
C57: 22n; C_0603_1608Metric_Pad1.08x0.95mm_HandSolder; Mouser Part Number GCE188R71H223KA01D
C58: 470n; C_0603_1608Metric_Pad1.08x0.95mm_HandSolder; Mouser Part Number 810-C1608X7R1H474K0E
C59, C60, C61, C62: 10n; C_0603_1608Metric_Pad1.08x0.95mm_HandSolder; Mouser Part Number 81-GCE188R71H103KA1D
D17: 40V/3A; D_SOD-123F; Mouser Part Number 637-SKL34
IC2: BTS722204ESAXUMA1; SOP65P600X115-25N; Mouser Part Number 726-BTS722204ESAXUMA
R44, R45, R46: 4k7; R_0603_1608Metric_Pad0.98x0.95mm_HandSolder; Mouser Part Number 71-CRCW0603-4.7K-E3
R47: 470R; R_0603_1608Metric_Pad0.98x0.95mm_HandSolder; Mouser Part Number 71-CRCW0603J-470-E3
R48, R49, R50, R51: 330R; R_0603_1608Metric_Pad0.98x0.95mm_HandSolder; Mouser Part Number 71-CRCW0603-330-E3
R52, R53, R54, R55: 10k; R_0603_1608Metric_Pad0.98x0.95mm_HandSolder; Mouser Part Number 71-CRCW060310K0FKEAH
R56: 1k2; R_0603_1608Metric_Pad0.98x0.95mm_HandSolder; Mouser Part Number 71-CRCW0603-1.2K-E3
R57: 47R; R_0603_1608Metric_Pad0.98x0.95mm_HandSolder; Mouser Part Number 71-RCS060347R0JNEA

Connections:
+3V3: R47.1; also elsewhere on the board
+BATT: C56.1, C57.1, IC2.25 (VS); also elsewhere on the board
/Connectors/OUT_ASSI: C60.1, IC2.19 (OUT1_1), IC2.20 (OUT1_2); also elsewhere on the board
/Connectors/OUT_EBS: C61.1, IC2.17 (OUT2_1), IC2.18 (OUT2_2); also elsewhere on the board
/Connectors/OUT_LIDAR: C59.1, IC2.21 (OUT0_1), IC2.22 (OUT0_2), IC2.23 (OUT0_3), IC2.24 (OUT0_4); also elsewhere on the board
/Connectors/OUT_RES: C62.1, IC2.13 (OUT3_1), IC2.14 (OUT3_2), IC2.15 (OUT3_3), IC2.16 (OUT3_4); also elsewhere on the board
/DV_power_supply/Dv_power_supply_component/CSN: IC2.6 (CSN), R51.2
/DV_power_supply/Dv_power_supply_component/IN0: IC2.8 (IN0), R52.2
/DV_power_supply/Dv_power_supply_component/IN1: IC2.9 (IN1), R53.2
/DV_power_supply/Dv_power_supply_component/IN2: IC2.10 (IN2), R54.2
/DV_power_supply/Dv_power_supply_component/IN3: IC2.11 (IN3), R55.2
/DV_power_supply/Dv_power_supply_component/IS: IC2.12 (IS), R46.2, R56.1
/DV_power_supply/Dv_power_supply_component/LHI: IC2.7 (LHI), R45.2
/DV_power_supply/Dv_power_supply_component/PC0_GND: C57.2, C58.1, IC2.1 (GND), R57.2
/DV_power_supply/Dv_power_supply_component/R_IS_PROT: D17.1 (K), R44.2, R46.1
/DV_power_supply/Dv_power_supply_component/SCLK: IC2.5 (SCLK), R50.2
/DV_power_supply/Dv_power_supply_component/SI: IC2.4 (SI), R49.2
/DV_power_supply/Dv_power_supply_component/SO: IC2.3 (SO), R48.2
/DV_power_supply/Dv_power_supply_component/VDD: C58.2, IC2.2 (VDD), R47.2
/DV_power_supply/FUSE_IS1: C55.1, R44.1; also elsewhere on the board
/DV_power_supply/LHI1: R45.1; also elsewhere on the board
/DV_power_supply/SPI1.CSN2: R51.1; also elsewhere on the board
/DV_power_supply/SPI1.MISO: R48.1; also elsewhere on the board
/DV_power_supply/SPI1.MOSI: R49.1; also elsewhere on the board
/DV_power_supply/SPI1.SCK: R50.1; also elsewhere on the board
GND: C55.2, C56.2, C59.2, C60.2, C61.2, C62.2, D17.2 (A), R52.1, R53.1, R54.1, R55.1, R56.2, R57.1; also elsewhere on the board

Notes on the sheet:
POWER CONTROLLER DV COMPONENTS
1* 0 [Ohm] or 330 [Ohm]
7A max
Optional
4A max

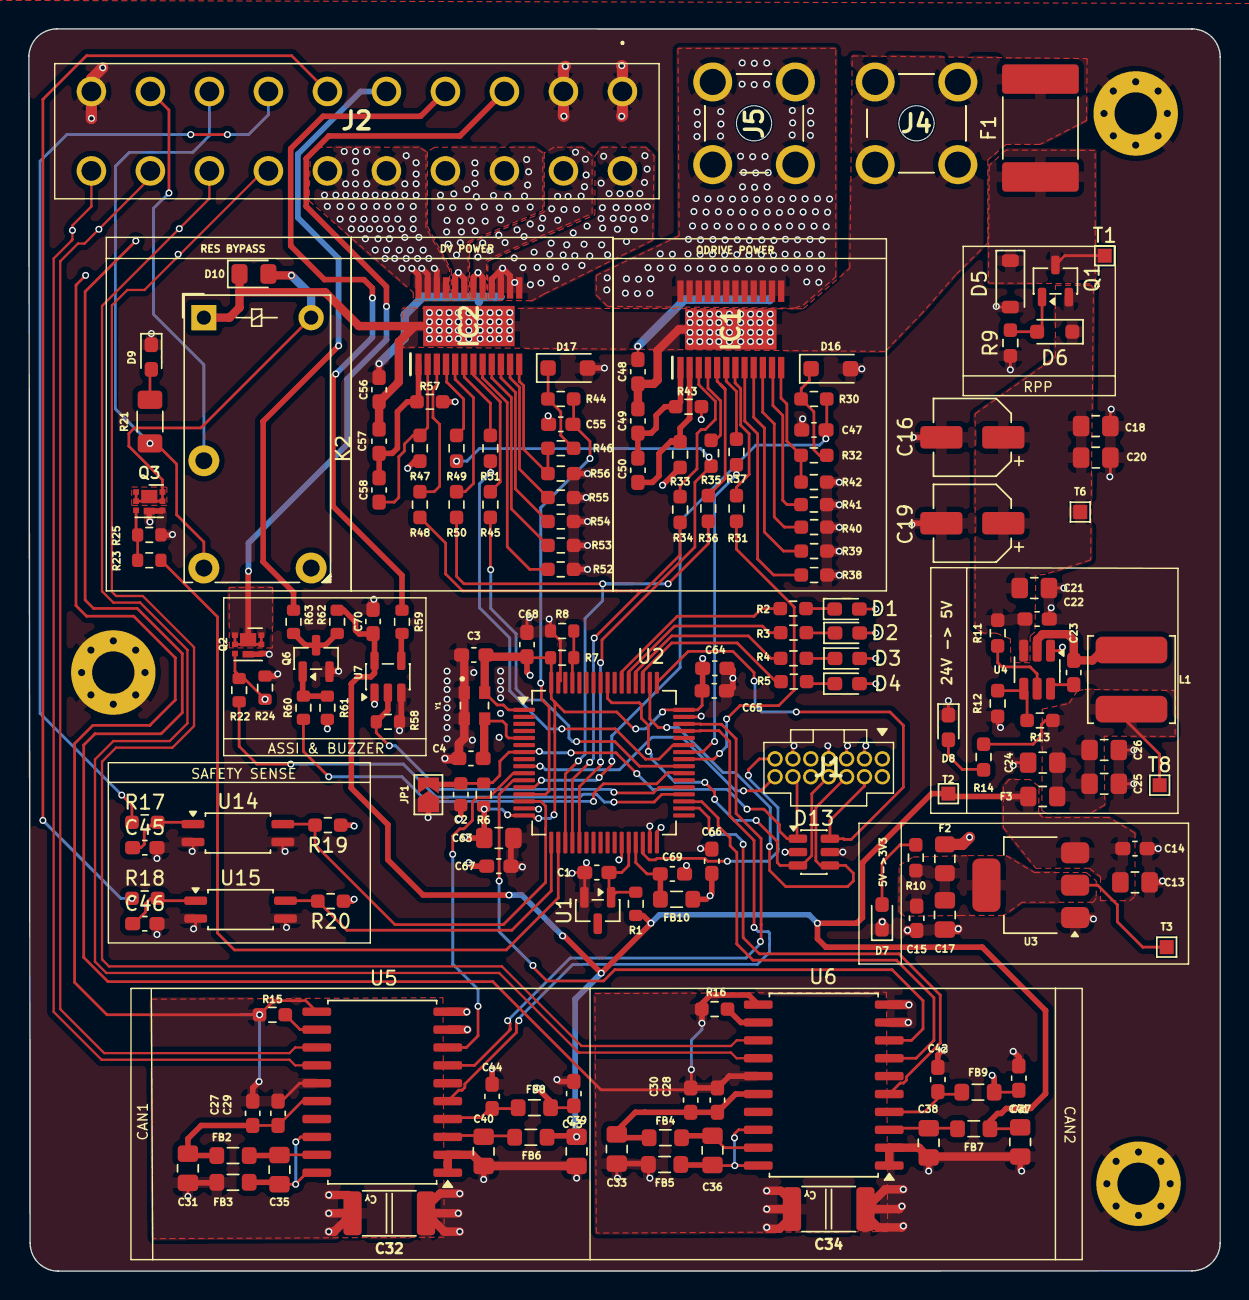
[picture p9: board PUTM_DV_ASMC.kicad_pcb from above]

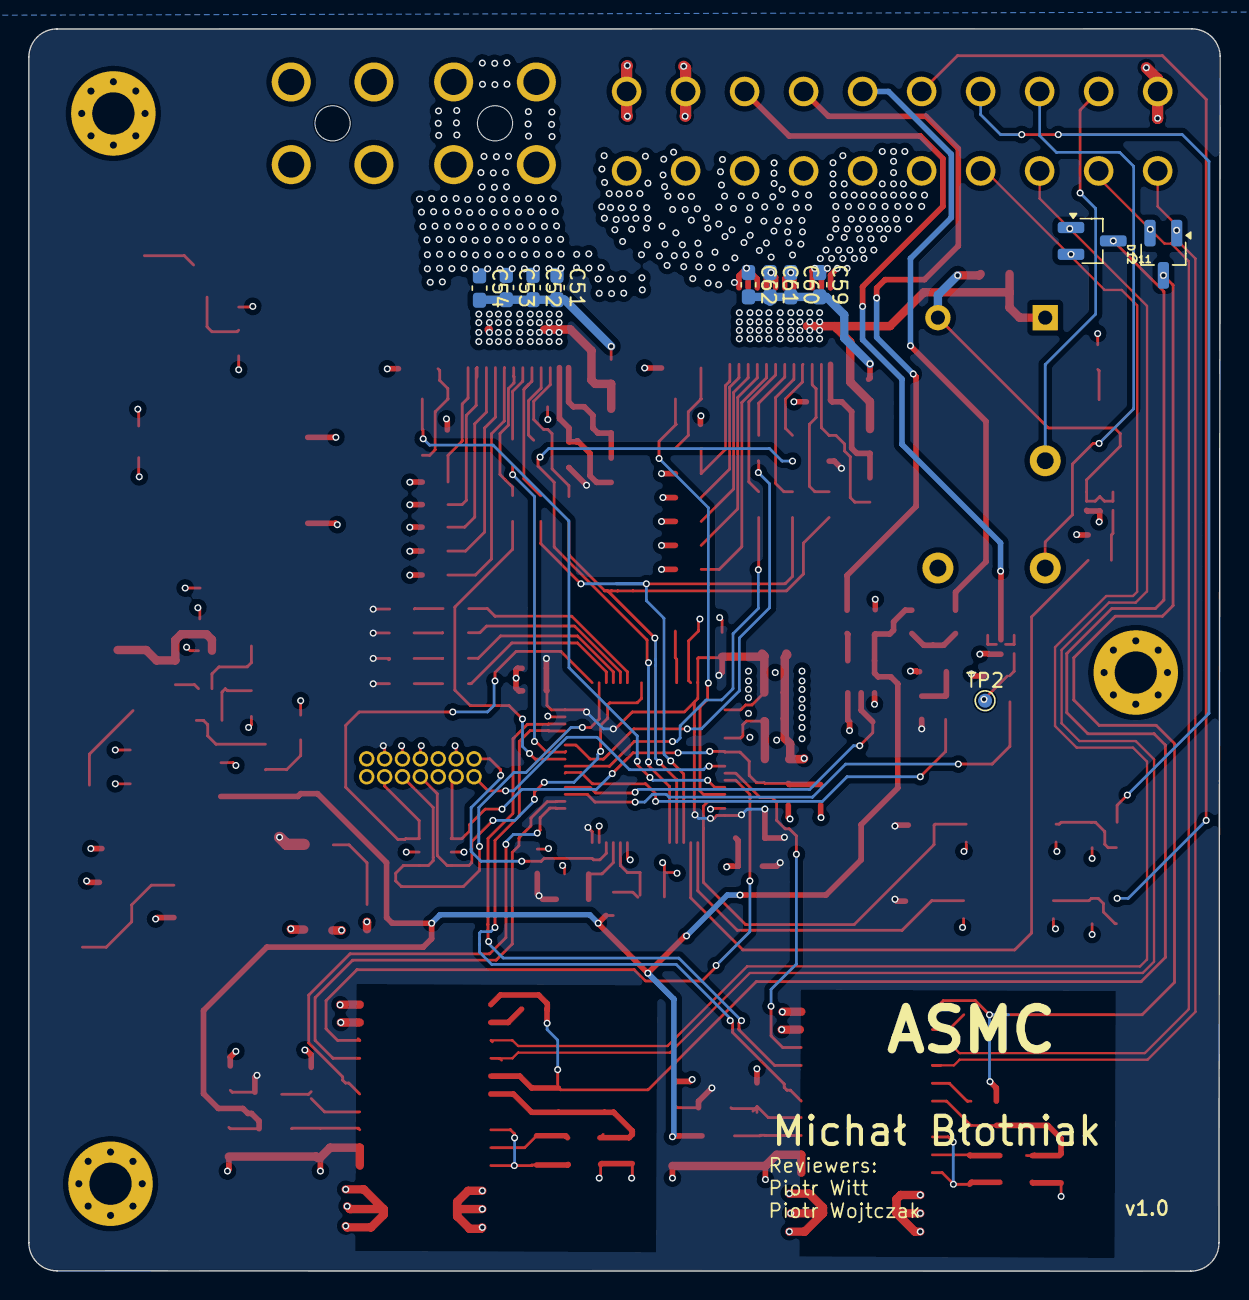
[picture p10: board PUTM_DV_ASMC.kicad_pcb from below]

Board: 4 copper layers, 84.6 x 88.2 mm, 177 parts (11 on the bottom side), 119 nets.

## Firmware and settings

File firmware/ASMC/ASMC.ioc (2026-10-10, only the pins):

Mcu.UserName=STM32G484RETx
PA0.GPIO_Label=FUSE_IS0
PA0.Signal=ADC1_IN1
PA1.GPIO_Label=FUSE_IS1
PA1.Signal=ADC2_IN2
PA11.Signal=FDCAN1_RX
PA12.Signal=FDCAN1_TX
PA13.Signal=SYS_JTMS-SWDIO
PA14.Signal=SYS_JTCK-SWCLK
PA15.GPIO_Label=DEBUG_LED_4
PA15.Signal=GPIO_Output
PA2.GPIO_Label=AS_SENSE
PA2.Signal=GPIO_Input
PA3.GPIO_Label=RES_SENSE
PA3.Signal=GPIO_Input
PA4.GPIO_Label=RES_BYPASS
PA4.Signal=GPIO_Output
PA5.Signal=SPI1_SCK
PA6.Signal=SPI1_MISO
PA7.Signal=SPI1_MOSI
PA8.GPIO_Label=SPI1_CSN1
PA8.Signal=GPIO_Output
PA9.GPIO_Label=SPI1_CSN2
PA9.Signal=GPIO_Output
PB0.Signal=ADC3_IN12
PB1.Signal=GPIO_Output
PB10.Signal=LPUART1_RX
PB12.Signal=FDCAN2_RX
PB13.Signal=FDCAN2_TX
PB14.GPIO_Label=BUZZER
PB14.Signal=GPIO_Input
PB15.GPIO_Label=ASSI_SIG1
PB15.Signal=SPI2_MOSI
PC1.Signal=LPUART1_TX
PC10.GPIO_Label=DEBUG_LED_3
PC10.Signal=GPIO_Output
PC11.GPIO_Label=DEBUG_LED_2
PC11.Signal=GPIO_Output
PC12.GPIO_Label=DEBUG_LED_1
PC12.Signal=GPIO_Output
PC2.GPIO_Label=STBY_CAN_1
PC2.Signal=GPIO_Output
PC3.GPIO_Label=STBY_CAN_2
PC3.Signal=GPIO_Output
PC7.GPIO_Label=ASSI_SIG2
PC7.Signal=GPIO_Output
PC8.GPIO_Label=LHI1
PC8.Signal=GPIO_Output
PC9.GPIO_Label=LHI0
PC9.Signal=GPIO_Output
PF0-OSC_IN.Signal=RCC_OSC_IN
PF1-OSC_OUT.Signal=RCC_OSC_OUT

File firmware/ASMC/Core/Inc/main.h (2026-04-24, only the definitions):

#define STBY_CAN_1_Pin GPIO_PIN_2
#define STBY_CAN_1_GPIO_Port GPIOC
#define STBY_CAN_2_Pin GPIO_PIN_3
#define STBY_CAN_2_GPIO_Port GPIOC
#define AS_SENSE_Pin GPIO_PIN_2
#define AS_SENSE_GPIO_Port GPIOA
#define RES_SENSE_Pin GPIO_PIN_3
#define RES_SENSE_GPIO_Port GPIOA
#define RES_BYPASS_Pin GPIO_PIN_4
#define RES_BYPASS_GPIO_Port GPIOA
#define SPI1_NSS_Pin GPIO_PIN_8
#define SPI1_NSS_GPIO_Port GPIOA
#define DEBUG_LED_1_Pin GPIO_PIN_4
#define DEBUG_LED_1_GPIO_Port GPIOB
#define DEBUG_LED_2_Pin GPIO_PIN_5
#define DEBUG_LED_2_GPIO_Port GPIOB
#define DEBUG_LED_3_Pin GPIO_PIN_6
#define DEBUG_LED_3_GPIO_Port GPIOB
#define DEBUG_LED_4_Pin GPIO_PIN_7
#define DEBUG_LED_4_GPIO_Port GPIOB
#define ASSI_DI_Pin GPIO_PIN_8
#define ASSI_DI_GPIO_Port GPIOB
#define ASSI_DO_Pin GPIO_PIN_9
#define ASSI_DO_GPIO_Port GPIOB

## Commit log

2026-03-26 make mcu section
    [ASIS.kicad_sch, Analog_Input.kicad_sch, CAN.kicad_sch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]
2026-04-19 assi section
    [ASIS.kicad_sch]
2026-04-19 io section
    [IO.kicad_sch]
2026-04-19 can section
    [CAN.kicad_sch]
2026-04-19 uC section work
    [Microcontroller.kicad_sch]
2026-04-24 schematics without main connector
    [ASIS.kicad_sch, Analog_Input.kicad_sch, CAN.kicad_sch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]
2026-05-28 done schematic v1
    [ASIS.kicad_sch, Connectors.kicad_sch, DV_power_supply.kicad_sch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]
2026-05-28 schematic without error
    [ASIS.kicad_sch, CAN.kicad_sch, Connectors.kicad_sch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]
2026-05-28 tylko dwa bledy z can - schemat na wykonczeniu
    [CAN.kicad_sch, Connectors.kicad_sch, Dv_power_supply_component.kicad_sch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]
2026-05-28 poprawki footprint
    [Connectors.kicad_sch, Dv_power_supply_component.kicad_sch, IO.kicad_sch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]
2026-05-29 work on power layout
    [Connectors.kicad_sch, PUTM_DV_ASMC.kicad_pcb]
2026-05-29 make function section
    [Connectors.kicad_sch, PUTM_DV_ASMC.kicad_pcb]
2026-05-29 update pins mcu
    [Microcontroller.kicad_sch, PUTM_DV_ASMC.kicad_pcb]
2026-05-30 make zones
    [Connectors.kicad_sch, IO.kicad_sch, PUTM_DV_ASMC.kicad_pcb]
2026-05-30 work on supply and zones
    [CAN.kicad_sch, Connectors.kicad_sch, DV_power_supply.kicad_sch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]
2026-05-30 work work work
    [CAN.kicad_sch, Connectors.kicad_sch, Microcontroller.kicad_sch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]
2026-05-30 can layout
    [Connectors.kicad_sch, Microcontroller.kicad_sch, PUTM_DV_ASMC.kicad_pcb]
2026-05-31 update pcb after review
    [CAN.kicad_sch, Microcontroller.kicad_sch, PUTM_DV_ASMC.kicad_pcb]
2026-06-01 pcb woithout iso gnd
    [PUTM_DV_ASMC.kicad_pcb]
2026-06-01 pcb 99.5proc
    [PUTM_DV_ASMC.kicad_pcb]
2026-06-01 pcb 100%
    [PUTM_DV_ASMC.kicad_pcb]
2026-10-03 update assi logic on schema and update .ioc
    [ASIS.kicad_sch, Connectors.kicad_sch, Microcontroller.kicad_sch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]
2026-10-03 update spi schema
    [CAN.kicad_sch, DV_power_supply.kicad_sch, Dv_power_supply_component.kicad_sch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]
2026-10-03 update pcb layout
    [ASIS.kicad_sch, PUTM_DV_ASMC.kicad_pcb]
2026-10-04 update pcb layout2
    [ASIS.kicad_sch, PUTM_DV_ASMC.kicad_pcb]
2026-10-04 update pcb layout3 - before review
    [PUTM_DV_ASMC.kicad_pcb]
2026-10-05 update pcb layout4 - before review
    [Microcontroller.kicad_sch, PUTM_DV_ASMC.kicad_pcb]
2026-10-05 update pcb layout5 - before review
    [Microcontroller.kicad_sch, PUTM_DV_ASMC.kicad_pcb]
2026-10-08 update pcb layout after rewiev
    [Dv_power_supply_component.kicad_sch, Microcontroller.kicad_sch, Odrive_power_supply.kicad_sch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]
2026-10-10 after review2
    [Connectors.kicad_sch, Microcontroller.kicad_sch, PUTM_DV_ASMC.kicad_pcb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]
2026-10-11 edit footprint for diode before manufactur - now product version

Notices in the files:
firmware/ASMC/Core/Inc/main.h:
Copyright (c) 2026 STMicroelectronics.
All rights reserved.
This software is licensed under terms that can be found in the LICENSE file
